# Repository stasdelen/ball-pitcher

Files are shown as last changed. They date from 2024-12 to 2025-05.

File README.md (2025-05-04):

# KingPong

Automatic table-tennis ball pitcher machine, developed as the main assignment of ME407 – Mechanical Engineering Design at Middle East Technical University. Designed to let a single player practice with realistic spin, speed and trajectory control.

## Media

### Team Demo at METU Showcase  
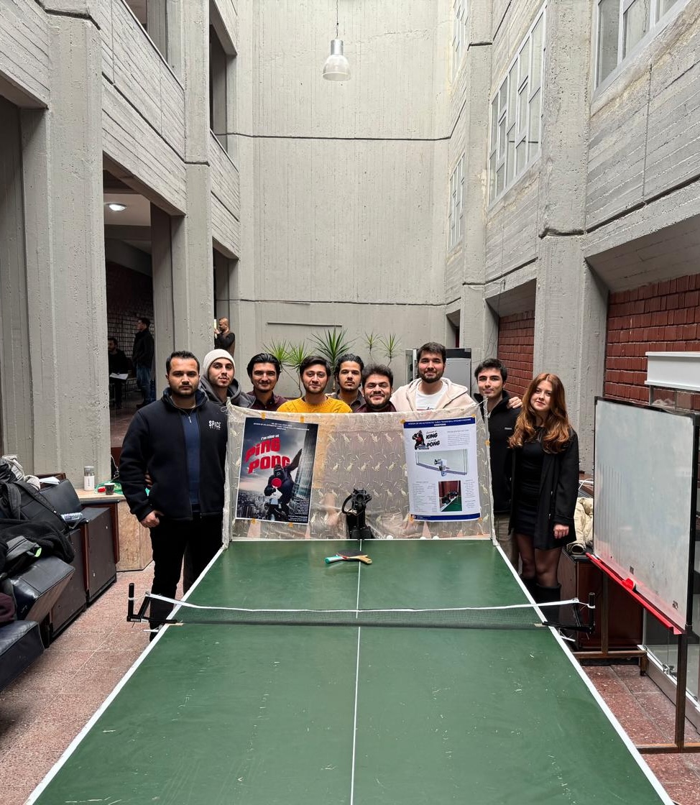
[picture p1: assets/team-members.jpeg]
Team Demo at METU Showcase
  
*The ME407 design group presenting their automatic table-tennis ball pitcher, KingPong, at the METU Mechanical Engineering Department exhibit.*

### METU Mechanical Engineering LinkedIn 
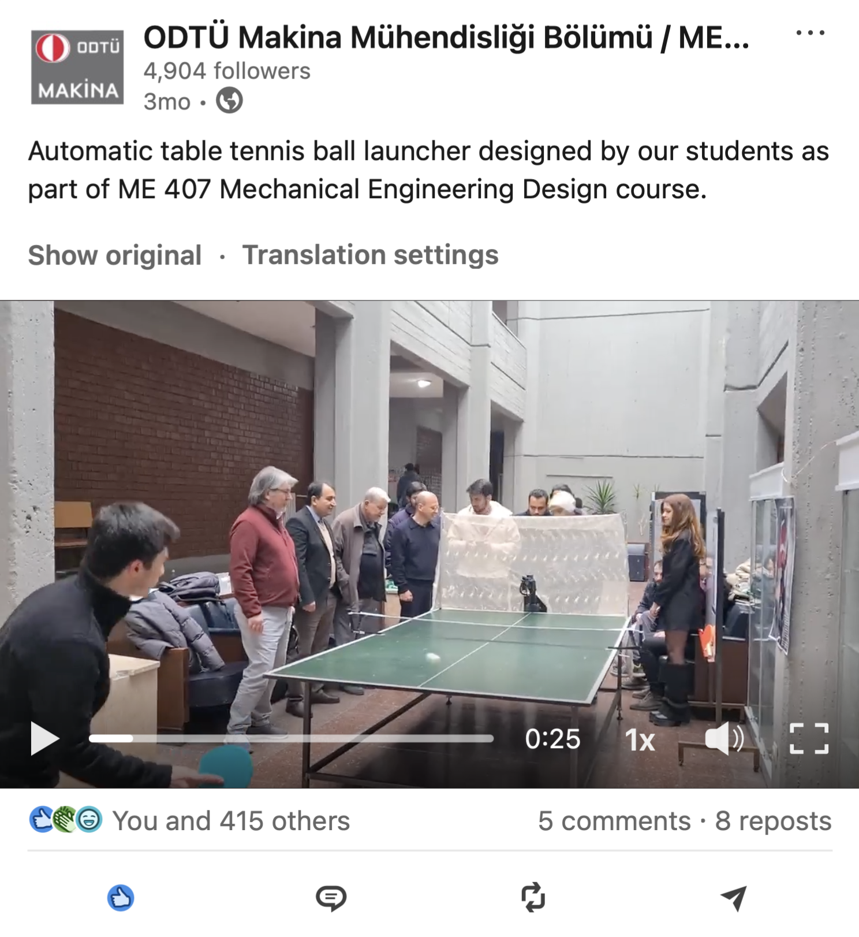
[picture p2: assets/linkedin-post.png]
METU Mechanical Engineering LinkedIn (https://www.linkedin.com/posts/odt%C3%BC-makina-m%C3%BChendisli%C4%9Fi-b%C3%B6l%C3%BCm%C3%BC-metu-department-of-mechanical-engineering_%C3%B6%C4%9Frencilerimizin-me-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)


### Pitching Mechanism Close-Up  
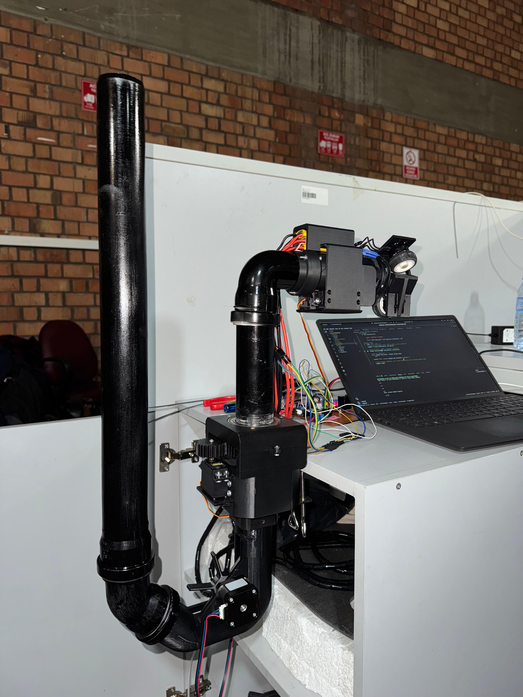
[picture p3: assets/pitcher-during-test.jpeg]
Pitching Mechanism Close-Up
  
*Detailed view of the dual-wheel launcher assembly with servo-driven feeder, control wiring, and live parameter tuning via the host laptop.*

### Mode Shape 3: Modal Analysis Result

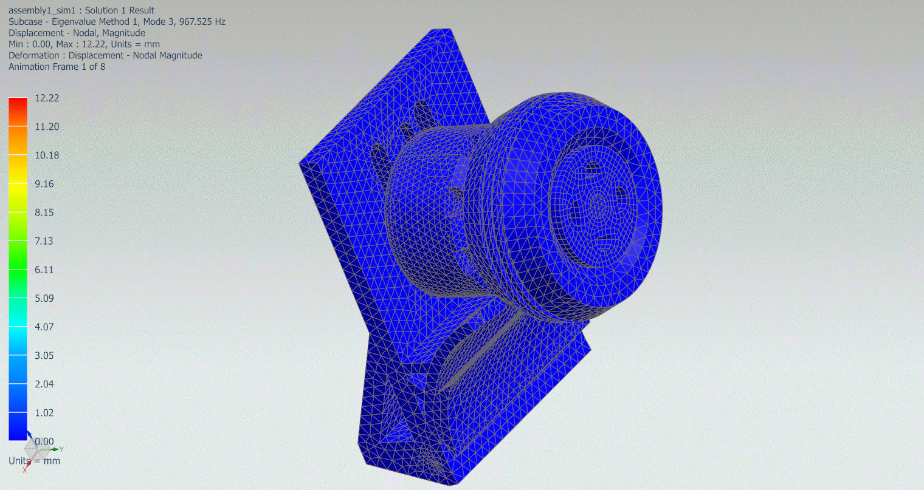
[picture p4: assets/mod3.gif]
Mode Shape 3 – Modal Analysis Result


*Figure: Mode shape 3 from the modal analysis of the spinning‐wheel assembly, illustrating the natural vibration pattern at its associated eigenfrequency.*

## Repository Structure

- **hardware/**  
  CAD models, mechanical drawings and BOM for the launcher, feeder and frame  
- **software/**  
  • `firmware/` Arduino code for motor, servo and sensor control  
  • `host/` Python scripts for remote parameter tuning and logging  
- **reports/**  
  Final report (FR_C1.pdf) and supporting calculations, test plans and sustainability analysis  
- **workshops/**  
  Presentation slides and in-class exercise materials  
- `.gitignore` Standard excludes for build artifacts  
- `.gitattributes` Line endings and diff settings  
- `LICENSE` MIT License  

## Key Features

- **Speed & Frequency** Adjustable launch speed up to 30 m/s and firing rate up to 60 balls/min  
- **Spin Control** Topspin, backspin, sidespin, or any combination of spins (and a no-spin “flat” option) via independent wheel speeds  
- **Trajectory** Pitch range 0 → –20°; yaw range ± 20°  
- **Capacity & Recycling** Reservoir holds ≥ 60 balls; returned balls are automatically fed back  
- **Size & Weight** Fits within 1 m³; total mass ≤ 25 kg  
- **Power** Runs on standard 220–240 V mains; < 2 kW peak consumption  

## Getting Started

1. **Assemble hardware** following the step-by-step CAD drawings in `hardware/`.  
2. **Flash firmware**: open `software/firmware/` in the Arduino IDE and upload to your controller board.  
3. **Launch host interface**: run `python3 software/host/control.py` to connect via USB or Wi-Fi and set speed, spin, pitch and yaw.  
4. **Consult report** in `reports/FR_C1.pdf` for detailed design rationale, calculations and test results.  

## Authors

- Abdullah Can Seyhanlı  
- Altay Ata Ateş  
- Arman Utku Aydın  
- Bilal Açıksöz  
- Kutay Can Yapıcı  
- Ömer Aslan  
- Özge Dilan Tuna
- Abdullah Salih Taşdelen  
- Yunus Emre Özçelik  

## License

This project is released under the MIT License.

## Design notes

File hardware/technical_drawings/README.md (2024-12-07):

# Technical Drawings of the Ball Pitcher

This folder contains the drafts/technicals drawings of the components and assemblies

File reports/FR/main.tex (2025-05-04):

\documentclass[12pt]{report}
\usepackage{graphicx} % For including graphics
\usepackage{hyperref} % For URLs and hyperlinks
\usepackage{amsmath} % For math symbols
\usepackage{enumitem} % For customized lists
\usepackage{geometry} % For page margins
\usepackage{xcolor} % For colored text
\usepackage{titlesec} % For title formatting
\usepackage{fancyhdr} % For headers
\usepackage{setspace} % For spacing
\usepackage{graphicx}
\usepackage{multirow}
\usepackage{adjustbox} % For scaling the table
\usepackage{array} % For defining column widths and centering
\usepackage{rotating}
\usepackage{pdfpages}

\usepackage{geometry} % For margin adjustments
\usepackage{booktabs} % For better looking tables
\usepackage{caption}
\usepackage{subcaption}
\usepackage{float}
\usepackage{rotating}      % For sideways tables
\usepackage{tabularx}      % For automatically adjusting column widths
\usepackage{enumitem}      % For controlling list spacing
\usepackage{placeins}  % For \FloatBarrier
\usepackage{caption}
\setcounter{tocdepth}{4}
\setcounter{secnumdepth}{4}

  %burası inş bozmaz bişi deniyorum şu an
\titleformat{\chapter}[hang]
  {\normalfont\huge\bfseries} % Yazı tipi ve boyutu
  {\thechapter}               % just numaraaa
  {1em}                       % bosluk
  {}                          % without ön ek
  %burası inş bozmaz bişi deniyorum şu an
  
% Page setup
\geometry{a4paper, margin=0.75in} % Adjust margins to allow more space
\setlength{\parindent}{0pt} % Remove indentation
\captionsetup{font=scriptsize}  % Change 'small' to any size: footnotesize, scriptsize, etc.

\renewcommand{\arraystretch}{1.2} % Adjusts the row height

% Title formatting with indentation for sections
% \titleformat{\section}{\bfseries\large\hspace*{1cm}}{\thesection.}{1em}{}
% \titleformat{\subsection}{\bfseries\hspace*{1cm}}{\thesubsection.}{1em}{}
% \titleformat{\subsubsection}{\bfseries\hspace*{2cm}}{\thesubsubsection.}{1em}{}

% Adjust paragraph indentation
\newenvironment{indentedsection}{
    \setlength{\parindent}{1cm} % Indent paragraphs
    \setlength{\leftskip}{1cm} % Indent entire section content
}{}

% Header setup
\pagestyle{fancy}
\fancyhf{}

\fancyhead[R]{\thepage}

% Horizontal line
\renewcommand{\headrulewidth}{0.4pt}

% Begin Document
\begin{document}

\vspace{1cm}

% METU Logo and Title
\begin{center}
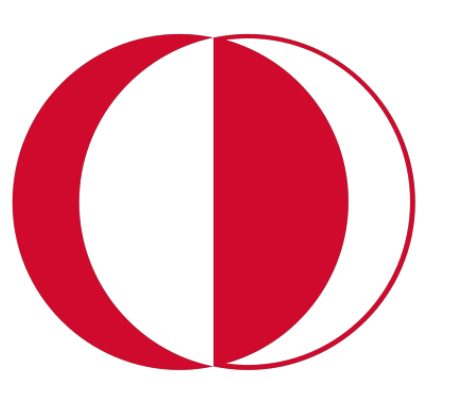
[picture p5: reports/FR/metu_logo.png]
     \\ % Replace "metu_logo.png" with the METU logo file
    \vspace{0.5cm}
    \textbf{\Large TABLE TENNIS BALL PITCHER MACHINE} \\
    \vspace{1cm}
\end{center}

% Report Title Section
\begin{center}
    \textbf{\Huge Final Report} \\
    \vspace{0.5cm}
    %\textbf{\large Subtitle (if any)} \\
    \vspace{1cm}
\end{center}

% Course and Instructor Details
\noindent
\textbf{Course Code and Name:} ME407 Mechanical Engineering Design \\
\textbf{Instructor:} Gökhan Özgen \\
\textbf{Semester:} Fall 2024 \\
\textbf{Date:} 10.01.2025 \\
\vspace{1cm}

% Group Member Details
\noindent
\textbf{Prepared by:}
\vspace{0.5cm}

\begin{center}
\scriptsize
    \begin{tabular}{|p{2cm}|p{1.5cm}|p{4cm}|p{2cm}|p{5cm}|}
        \hline
        \textbf{Name} & \textbf{Student Number} & \textbf{Student E-Mail} & \textbf{Phone Number} & \textbf{Adress}\\ \hline
        Abdullah Can Seyhanlı & 2446821 & abdullah.seyhanli@metu.edu.tr & +905346688387 & Üniversiteler Mah. ODTÜ 8. Yurt 312/3 Ankara/Çankaya \\ \hline
        Altay Ata Ateş & 2445476 & altay.ates@metu.edu.tr & +905422322415 & Üniversiteler Mahallesi ODTÜ Kümeevleri NO: 58 ( Refika Aksoy Yurdu ) Çankaya/Ankara \\ \hline
        Arman Utku Aydın & 2445492 & utku.aydin@metu.edu.tr & +905375432848 & İşçi blokları mahallesi 1538/1. sokak No:23 Daire:6 \\ \hline
        Bilal Açıksöz & 2445286 & bilal.aciksoz@metu.edu.tr & +905437451151 & Kavacık Subayevleri mah. Ergün sok. No:14/2 Keçiören/Ankara \\ \hline
        Kutay Can Yapıcı & 2447084 & kutay.yapici@metu.edu.tr & +905383026603 & Karşıyaka mah. 464. sok. No:24/99 Gölbaşı/Ankara \\ \hline
        Ömer Aslan & 2445443 & omer.aslan\_01@metu.edu.tr & +905532456710 & Üniversiteler Mah. ODTÜ 19.Yurt 329/2 Çankaya/Ankara \\ \hline
        Özge Dilan Tuna & 2446987 & ozge.tuna@metu.edu.tr & +905532611838 & Anadolu Blv. Mehmet Akif Ersoy Mah. Yeşilay Cad. No:5 Yenimahalle/Ankara \\ \hline
         Abdullah Salih Taşdelen & 2446904 & salih.tasdelen@metu.edu.tr & +905541371310 & Yeni Etlik Cad. No: 84/9 Kecioren/Ankara \\ \hline
        Yunus Emre Özçelik & 2268803 & ozcelik.yunus@metu.edu.tr&+905529200972 & Yüzbaşı Mustafa Ertuğrul Cd. Şeker Mah. Eryaman Etimesgut/Ankara \\ \hline
    \end{tabular}
\end{center}

\vfill

% Footer Section
\begin{center}
    \textbf{Location: Ankara, Turkey}
\end{center}

\tableofcontents

\section*{Nomenclature}
\begin{table}[H]
\centering
\begin{tabular}{|c|l|}
\hline
\textbf{Symbol} & \textbf{Description} \\ \hline
$\omega$        & Angular velocity          \\ \hline
$V$             & Linear velocity           \\ \hline
$r$             & Radius                    \\ \hline
$s$             & Slip amount               \\ \hline
$I$             & Inertia                   \\ \hline
$t$             & Time                      \\ \hline
$E_p$           & Potential Energy          \\ \hline
$P$             & Power, Load               \\ \hline
$\alpha, \theta$ & Angle                     \\ \hline
$m$             & Mass, Module              \\ \hline
$F$             & Force                     \\ \hline
$z$             & Teeth number              \\ \hline
$d$             & Diameter                  \\ \hline
$b$             & Face width                \\ \hline
$h$             & Working depth             \\ \hline
$h_a$           & Addendum                  \\ \hline
$h_f$           & Dedendum                  \\ \hline
$R_{xy}$        & Gear ratio                \\ \hline
$X, Y$          & Load factor               \\ \hline
$n$             & Rotational speed (rpm)    \\ \hline
$v$             & Viscosity                 \\ \hline
$T$             & Temperature, Torque       \\ \hline
$A$             & Area                      \\ \hline
$C$             & Basic dynamic load rating \\ \hline
$p$             & Exponent of life equation \\ \hline
$L$             & Basic rating life         \\ \hline
$g$             & Acceleration due to gravity \\ \hline
$\text{FoS}$    & Factor of safety          \\ \hline
$\text{UTS}$    & Ultimate tensile strength \\ \hline
$S_y$           & Yield strength            \\ \hline
$J$             & Polar moment of inertia   \\ \hline
$\sigma$        & Stress                    \\ \hline
$E$             & Elastic modulus           \\ \hline
$k$             & Stiffness                 \\ \hline
$l$             & Length                    \\ \hline
$n_b$           & Safety factor             \\ \hline
$n_o$           & Separation factor         \\ \hline
$M$             & Bending moment            \\ \hline
\end{tabular}
\caption{Symbols and their Descriptions}
\label{tab:symbols}
\end{table}
\section*{Lists}

\begin{table}[h!]
\centering
\begin{tabular}{|p{15cm}|}
\hline
\textbf{List of Tables} \\ \hline
Table 4.1: Comparison of Table Tennis Robots \\ \hline
Table 5.1: The Members of the Project \\ \hline
Table 5.2: Timetable Showing Workload Distribution \\ \hline
Table 7.1: Yaw Angle Components \\ \hline
Table 7.2: Feeding System Components \\ \hline
Table 7.3: Decisions Based on Meeting the Performance Criteria Target (Part 1) \\ \hline
Table 7.4: Decisions Based on Meeting the Performance Criteria Target (Part 2) \\ \hline
Table 7.5: Gear Dimensions \\ \hline
Table 7.6: Decisions Based on Meeting the Performance Criteria Target (Part 3) \\ \hline
Table 7.7: Specifications of the 17HS3401S Motor \\ \hline
Table 7.8: Failure Scenarios and Related Design Parameters \\ \hline
Table 7.9: List of Final Values of Design Decisions and Parameters\\ \hline
Table 10.1: Cost Analysis \\ \hline
\end{tabular}
\caption{List of Tables}
\label{tab:list_of_tables}
\end{table}

\begin{table}[h!]
\centering
\begin{tabular}{|p{15cm}|}
\hline
\textbf{List of Figures} \\ \hline
Figure 4.1: Table tennis equipment wholesale sales in the U.S. from 2007 to 2023 [7] \\ \hline
Figure 4.2: Sectional view of the ball feeding flow from the reservoir to launch unit in AIMY [9] \\ \hline
Figure 4.3: General System Description [1] \\ \hline
Figure 4.4: General schematic of
serving machine [2] \\ \hline
Figure 4.5: Side view and detailed
mechanism of table tennis robot [3] \\ \hline
Figure 4.6: Orthogonal and general views of the table tennis robot [3] \\ \hline
Figure 4.7: General System Description [4] \\ \hline
Figure 4.8: Lower to Upper-Level Reservoir Feeding System [5] \\ \hline
Figure 5.1: Gantt Chart \\ \hline
Figure 6.1: Functional Decomposition \\ \hline
Figure 6.2: Free body diagram of the ball \\ \hline
Figure 6.3: Criteria vs Criteria Evaluation
\\ \hline
Figure 6.4: Criteria vs Criteria Evaluation Normalized \\ \hline
Figure 6.5: Giving spin to the ball \\ \hline
Figure 6.6: Controlling the spin \\ \hline
Figure 6.7: Giving speed to the ball \\ \hline
Figure 6.8: Controlling the speed \\ \hline
Figure 6.9: Giving yaw angle to the launching mechanism \\ \hline
Figure 6.10: Controlling the yaw angle \\ \hline
Figure 6.11: Giving pitch angle to the launching mechanism \\ \hline
Figure 6.12: Controlling the pitch angle \\ \hline
Figure 6.13: Accepting frequency information from the user \\ \hline
Figure 6.14: Accepting numerical information from the user \\ \hline
Figure 6.15: Accepting trajectory information from the user \\ \hline
Figure 6.16: Allowing the user to position the device \\ \hline
Figure 6.17: Preventing balls from escaping \\ \hline
Figure 6.18: Storing the balls \\ \hline
Figure 6.19: Transferring the balls from the storage \\ \hline
Figure 6.20: Controlling the ball feed for storage \\ \hline
Figure 6.21: Transferring the balls to launch \\ \hline
Figure 6.22: Controlling the ball feed for launching \\ \hline
Figure 6.23: Giving the balls desired frequency \\ \hline
Figure 6.24: Controlling the ball frequency
\\ \hline
Figure 6.25: Concept Evaluation Normalized[6] \\ \hline
Figure 6.26: Feeder side view\\ \hline
Figure 6.27: Side view \\ \hline
Figure 6.28: Front View \\ \hline
Figure 6.29: Orthogonal view \\ \hline

\end{tabular}
\caption{List of Figures (Part 1)}
\label{tab:list_of_figures_part1}
\end{table}

\begin{table}[h!]
\centering
\begin{tabular}{|p{15cm}|}
\hline
\textbf{List of Figures} \\ \hline
Figure 7.1: Launcher Subassembly \\ \hline
Figure 7.2: Pitch angle subassembly \\ \hline
Figure 7.3: Yaw angle subassembly \\ \hline
Figure 7.4: 6810 ZZ Bearing \\ \hline
Figure 7.5: Feeding system subassembly \\ \hline
Figure 7.6: Socket head bolt \\ \hline
Figure 7.7: Set screw \\ \hline
Figure 7.8: Ball Recyclability system \\ \hline
Figure 7.9: Storage system subassembly \\ \hline
Figure 7.10: Clamp \\ \hline
Figure 7.11: FBD of launcher subassembly \\ \hline
Figure 7.12: Gear kinematics \\ \hline
Figure 7.13: Calculation factors for deep groove ball bearings \\ \hline
Figure 7.14: Rated viscosity estimation table \\ \hline
Figure 7.15: Viscosity value table\\ \hline
Figure 7.16: a\_skf factor\\ \hline
Figure 7.17: Selection of a1 factor\\ \hline
Figure 7.18: Free-body diagram of Maltese wheel\\ \hline
Figure 7.19: Model of inclined groove\\ \hline
Figure 7.20: Buckling condition constants\\ \hline
Figure 7.21: FBD of Bolt\\ \hline
Figure 7.22: FBD of the Clamp Connection\\ \hline
Figure 7.23: Analysis result of feeding holder\\ \hline
Figure 7.24: Analysis result of Maltese wheel\\ \hline
Figure 7.25: Analysis result of main body below part\\ \hline
Figure 7.26: Analysis result of upper elbow\\ \hline
Figure 7.27: Analysis result of the pitch angle fixed part\\ \hline
Figure 7.28: Main flow chart\\ \hline
Figure 7.29: BLDC Motor Control flow chart\\ \hline
Figure 7.30: Stepper motor control flow chart\\ \hline
Figure 7.31: Yaw and pitch angle control flow chart\\ \hline
Figure 7.32: Results of the Environmental Impact Analysis\\ \hline
Figure 11.1: Storing Mechanisms\\ \hline
Figure 11.2: Transferring the balls from storage\\ \hline
Figure 11.3: Giving the balls desired frequency\\ \hline
Figure 11.4: Net\\ \hline
Figure 11.5: Gravity Mechanism\\ \hline
Figure 11.6: Giving spin and speed to the balls\\ \hline
Figure 11.7: Giving pitch angle to the launching mechanism\\ \hline

\end{tabular}
\caption{List of Figures (Part 2)}
\label{tab:list_of_figures_part2}
\end{table}
\begin{table}[h!]
\centering
\begin{tabular}{|p{15cm}|}
\hline
\textbf{List of Figures} \\ \hline
Figure 11.8: Giving yaw angle to the launching mechanism\\ \hline
Figure 11.9: Accepting spin and frequency information from the user\\ \hline
Figure 11.10: Accepting speed information from the user\\ \hline
Figure 11.11: Clamps\\ \hline
Figure 11.12: Technical drawing of the assembly of the system\\ \hline
Figure 11.13: Technical drawing of the feeding holder\\ \hline
Figure 11.14: Technical drawing of the yaw motor housing\\ \hline
Figure 11.15: Technical drawing of the hole bearing cap\\ \hline
Figure 11.16: Technical drawing of the storage\\ \hline
Figure 11.17: Technical drawing of the feeding line to storage\\ \hline
Figure 11.18: Technical drawing of the flywheel\\ \hline
Figure 11.19: Technical drawing of the groove\\ \hline
Figure 11.20: Technical drawing of the keyway bushing for yaw mechanism\\ \hline
Figure 11.21: Technical drawing of the bottom part of the main body\\ \hline
Figure 11.22: Technical drawing of the upper part of the main body\\ \hline
Figure 11.23: Technical drawing of the Maltese wheel\\ \hline
Figure 11.24: Technical drawing of the slotted pipe for the launcher head\\ \hline
Figure 11.25: Technical drawing of the pipe attachment for launcher head\\ \hline
Figure 11.26: Technical drawing of the motor attachment for the launcher head\\ \hline
Figure 11.27: Technical drawing of the fixed part for pitch angle\\ \hline
Figure 11.28: Technical drawing of the moving part for pitch angle\\ \hline
Figure 11.29: Bill of materials to be bought\\ \hline
Figure 11.30: Bill of materials to be manufactured\\ \hline
Figure 11.31: Route sheets for the components\\ \hline
Figure 11.32: Control schematic of the system\\ \hline

\end{tabular}

\caption{List of Figures (Part 3)}
\label{tab:list_of_figures_part3}
\end{table}

\chapter{Abstract}
This project is performed as the main assignment of the course ME407 Mechanical Engineering Design at Middle East Technical University. Purpose of this course is to familiarize the students in their final year with the processes of engineering design, enhance their problem solving and decision-making skills, introduce them to the use of different software tools for design, and teach them planning, management and teamwork. The objective for this project is to design an Automatic Table Tennis Ball Pitcher Machine suitable to use for players of all ages and skill levels to practice on their own. First, a literature survey is conducted to study the existing products on the market, state of the art technologies and the patents related to the project. Then the requirements of the project are determined considering the goal, including but not limited to being able to give different spin options, varying yaw and pitch angles and different speeds. The design criteria are then set according to these requirements. Next, the planning for the management for the project is done, where tasks are assigned to each group member according to their different capabilities. In the conceptual design process, different concepts and ideas to perform the necessary functions are created and evaluated. A functional decomposition is performed and a morphological chart is constructed for this purpose, and the evaluation is performed using Analytic Hierarchy Process method. The resultant design is named the best design for the project, and the detailed design process is initiated. The detailed design process consists of performing the necessary analyses and calculations for the parts and components that fulfill the functions as decided on the best design to justify their working mechanisms, performing the optimization procedures where they are due, conducting the necessary tests and finally the manufacturing and assembly of these parts and the whole system in general. The whole process is documented along the way, with the technical drawings of the project, the machine elements used, the standards followed, the cost analysis and sustainability report. This project presented an important opportunity to work on a real-life engineering case, and get acquainted with the hardships and scenarios encountered in practical applications. The experience gained along the way is valuable for all members involved.
\chapter{Özet}
Bu proje, Orta Doğu Teknik Üniversitesi’nde ME407 Makina Mühendisliği Dizaynı dersinin ana görevi olarak yapılmıştır. Bu dersin amacı, son senesindeki öğrencileri mühendislik dizaynı süreçlerine alıştırmak, problem çözme ve karar alma becerilerini geliştirmek, dizayn için çeşitli yazılım araçlarının kullanımıyla tanıştırmak ve onlara planlama, yönetim ve takım çalışmasını öğretmektir. Bu projenin amacı, her yaştan ve beceri düzeyinden oyuncunun kendi başına pratik yapabilmesi için kullanıma uygun bir Otomatik Masa Tenisi Topu Fırlatıcısı makinesi dizayn etmektir. Öncelikle, projeyle alakalı piyasada var olan ürünleri, son teknolojileri ve patentleri incelemek için bir literatür taraması gerçekleştirilmiştir. Sonrasında, projenin amacı göz önünde bulundurularak, topa farklı dönüş opsiyonları, değişken yatay ve dikey fırlatış açıları ve farklı hızlar vermeyi içeren, fakat bunlarla sınırlı olmayan gereksinimlere karar verilmiştir. Sonrasında bu gereksinimlere göre dizayn kriterleri oluşturulmuştur. Sonrasında, her grup üyesine farklı kabiliyetlerine uygun görevlerin verildiği, projenin yönetimi için gereken planlama yapılmıştır. Konsept dizaynı sürecinde, gerekli fonksiyonları gerçekleştiren farklı konseptler ve fikirler oluşturulup değerlendirilmiştir. Bu amaç için bir hiyerarşik ayrıştırma yapılmış ve bir morfolojik şema oluşturulmuş, değerlendirme için de Analitik Hiyerarşi Süreci metodu kullanılmıştır. Sonuçlanan dizayn en iyi dizayn olarak adlandırılmış, ve detaylı dizayn süreci başlamıştır. Detaylı dizayn süreci, en iyi dizaynda karar verildiği gibi fonksiyonları gerçekleştiren kısım ve parçaların çalışma mekanizmalarını doğrulamak için gerekli analizlerin ve fonksiyonların yapılmasından, gereken yerlerde optimizasyon prosedürlerinin uygulanmasından, gerekli testlerin gerçekleştirilmesinden ve nihayetinde bu kısımların ve genel sistemin üretimi ve montajından oluşmaktadır. Bütün bu süreç aynı zamanda teknik çizimlerle, kullanılan makine elemanlarıyla, takip edilen standartlarla, maliyet analiziyle ve sürdürülebilirlik raporuyla birlikte belgelendirilmiştir. Bu proje, gerçek bir mühendislik vakasında çalışmak, ve pratik uygulamada karşılaşılan zorluk ve senaryolarla tanışmak konusunda önemli bir imkan sunmuştur. Bu süreçte kazanılan deneyim, dahil olan tüm üyeler için önemlidir.

\chapter{Introduction}

Table tennis is a sport that keeps rising in popularity day by day, as it can be easily enjoyed by all age groups, and the rules are easy to pick up. Aside from being an Olympic sport, it is also
widely played as a hobby by a large number of people, and some studies even suggest that for
children and the elderly, the sport has various physical and mental health benefits. Taking these
into consideration, it can be seen in \ref{fig:intro} that the demand for the sport is increasing each year.
\begin{figure}[h!]
    \centering
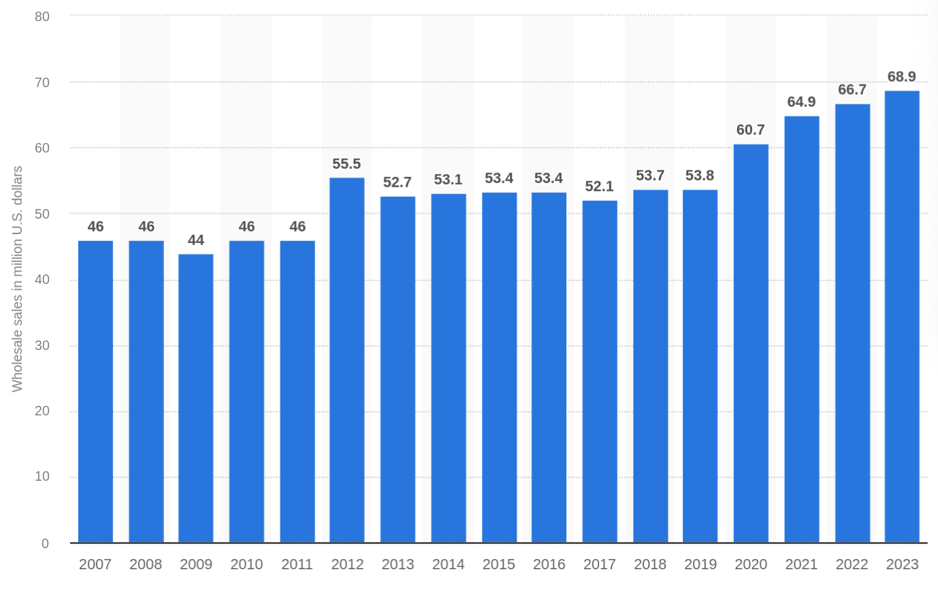
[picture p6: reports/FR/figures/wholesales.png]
    
    \caption{Table tennis equipment wholesale sales in the U.S. from 2007 to 2023 \cite{statista2024}}
    \label{fig:intro}
\end{figure}

For such a popular sport that spans from a professional and competitive scene to a leisure time hobby for a large demographic, a prominent issue may be expressed as its requirement of two people to be played. A willing partner to practice with may not be readily available at all times, and this poses a problem for both professional players who need to practice and hone their skills for competition, and the general population who seek to play it for various reasons ranging from pastime hobby to a healthy lifestyle. For this reason, the need for a product that allows people to practice the sport on their own is apparent. However, the already existent products on the market are either too expensive to serve a broader customer population or lack some features that may result in a poorer experience. This project aims to fill the gap and create a table tennis ball pitching machine suitable for players of all skill levels, from amateur to professional.

To accomplish this goal and imitate a real play experience as closely as possible, certain requirements should be met. These requirements include but are not limited to, the machine being able to automatically adjust its yaw and pitch angles, perform simple and basic pitches while also being able to give various spin options, launch the ball at different speeds and frequencies, as well as switching between these variations automatically. The machine should also be able to store a minimum number of balls, and recycle successfully returned balls into the system via some mechanism. Considering these requirements, design specifications and criteria can be constructed as follows:

\begin{itemize}
    \item The ball must reach a maximum speed of 30 m/s during launch. It must be adjustable within this range.
    \item The ball’s launch frequency must provide 60 balls per minute. It must be adjustable within this range.
    \item The ball must be able to be given spin up to 500 RPM, including backspin, topspin, sidespin, and their derivatives. This spin value must be independent of speed.
    \item The launcher must provide launch with a yaw angle within a range of ±20 degrees horizontally.
    \item The launcher must provide launch with a pitch angle within a range of 0 to -20 degrees vertically.
    \item A storage area that can accommodate a minimum of 60 balls is required.
    \item The maximum weight of the entire system must not exceed 25 kilograms.
    \item The system is securely fastened to the table or floor in the middle of the opponent’s side of the ITTF standard table, at the center of the width of the table. The maximum displacement after 50 throws shall be 20 mm.
    \item The lifetime of a single ball in the cycle should be at least 1000 throws.
    \item The system must have a user interface allowing launch parameter configuration with a maximum 10\% deviation.
    \item The design can collect the properly returned balls from the player. Recyclable ball height needs to be at least 1 meter.
    \item The system is compliant with ITTF table and ball dimensions:
    \begin{itemize}
        \item Suitable for a 2.74 m long and 1.525 m wide table.
        \item Can serve over a 15.25 cm high net.
        \item Suitable for standard table tennis balls with a 2.7-gram weight and 40 mm diameter.
    \end{itemize}
    \item The machine should operate on standard mains electricity (220-240V, 50-60 Hz). Also, it should not consume more than 2000W.
    \item Total spending for the prototype of the design should be kept within 300 USD.
    \item The design, when unassembled, should fit inside a 1 m\textsuperscript{3} box.
    \item \textbf{(Bonus)} The ball must be able to be thrown without spin.
    \item \textbf{(Bonus)} The ball is first bounced by the shooter, giving the user the experience of serving.
\end{itemize}

\begin{table}[H]
\centering
\begin{tabular}{|c|p{7cm}|c|}
\hline
\textbf{\#} & \textbf{Design Criteria} & \textbf{Percentage} \\ \hline
1 & Serving Speed & 13\% \\ \hline
2 & Throwing Frequency & 13\% \\ \hline
3 & Spin Type and Amount & 10\% \\ \hline
4 & Yaw Angle Adjustment & 7\% \\ \hline
5 & Pitch Angle Adjustment & 7\% \\ \hline
6 & Storage Capacity & 6\% \\ \hline
7 & Weight & 4\% \\ \hline
8 & Stability of the System & 6\% \\ \hline
9 & Ball Durability & 4\% \\ \hline
10 & Control Accuracy and Output Consistency & 7\% \\ \hline
11 & Ball Recyclability & 5\% \\ \hline
12 & Compliancy with Standards & 3\% \\ \hline
13 & Power Consumption & 3\% \\ \hline
14 & Budget & 8\% \\ \hline
15 & Portability & 4\% \\ \hline
16 & No Spin Option (Bonus) & 5\% \\ \hline
17 & Special Serving (Bonus) & 5\% \\ \hline
\end{tabular}
\caption{Design Criteria and Their Percentages}
\label{tab:design_criteria}
\end{table}

The design for this project starts with a thorough literature survey conducted on products on the market, state-of-the-art technologies and patents related. Then, a detailed task distribution and management plan is done spanning the whole project process, which helps lay out a road map and makes it easier to organize and handle the work for further down the line. The conceptual design starts at this point, where ideas and concepts begin to appear, which are listed and evaluated using methods such as performing functional decomposition, creating a morphological chart and passing them through Analytical Hierarchy Process. After a best design is chosen through these processes, the detailed design part is initiated. In this part, necessary analyses and calculations are performed to justify the design, the test plans are made and test are carried out, and components and parts are manufactured accordingly. Optimization processes are done where necessary. At the end of this part, a fully assembled and working system is expected to be constructed. The whole design process is documented from start to finish, with important information such as technical drawings, cost analysis and sustainability report included, to create a clear and concise report so as the design process and the design itself could be understood. 

This final report is the combination of all the reports created up until this point for different parts of the design process. A discussion and conclusion is given at the end of the report, where the final product is discussed, and conclusions derived are mentioned. The references part, where the sources made use of and referred and the appendix part, where the necessary appendices are presented are also given at the end. The outline of the final report is given as,

\begin{enumerate}
    \item \textbf{Abstract}
    \item \textbf{Introduction}
    \item \textbf{Literature Survey}
    \begin{enumerate}
        \item[a.] Introduction
        \item[b.] Commercial Products
        \item[c.] State-of-the-art on Related Technologies
        \item[d.] Patents
        \item[e.] Summary and Conclusion
    \end{enumerate}
    \item \textbf{Project Planning and Management}
    \begin{enumerate}
        \item[a.] Introduction
        \item[b.] Organization of the Project
        \item[c.] Summary and Conclusion
    \end{enumerate}
    \item \textbf{Conceptual Design}
    \begin{enumerate}
        \item[a.] Introduction
        \item[b.] Concept Development and Presentation
        \item[c.] Evaluation of Concepts
        \item[d.] Best Concept
        \item[e.] Summary and Conclusion
    \end{enumerate}
    \item \textbf{Detailed Design}
    \begin{enumerate}
        \item[a.] Introduction
        \item[b.] Properties of the Designed System
        \item[c.] Engineering Calculations
        \item[d.] Analysis Results
        \item[e.] Discussion of Control Algorithms and Software
        \item[f.] Optimization
        \item[g.] System to be Manufactured
        \item[h.] Sustainability Analysis
        \item[i.] Test Plan
        \item[j.] Standards Used for Design Procedures and Performance Evaluation
        \item[k.] Discussion and Conclusion
    \end{enumerate}
    \item \textbf{Discussion}
    \item \textbf{Conclusion}
    \item \textbf{References}
    \item \textbf{Appendix}
\end{enumerate}

\chapter{Literature Survey}

% Main title and keyword section
\begin{center}
    \vspace{1em} % Add some space
    \vspace{1em} % Add some space
    \textbf{KEYWORDS: Table Tennis, Ball Thrower, Ball Collector, Trajectory Control, Ping Pong Spin}
\end{center}

% Start of sections
\section{Introduction}

For this project of a table tennis pitching machine, a detailed literature survey that includes the research of commercial products available in the market, state of the art technologies and the patents is conducted. As the market for table tennis is wide and open for profit, there are already numerous of products and technologies on how to approach different aspects of the project.\\

For commercial products, different table tennis ball pitching machines on the market are observed and analyzed to get an idea about their capabilities and shortcomings. It is necessary to choose which features to implement based on the demand of the market and the cost-effectiveness of the end product. \\

The state-of-the-art technologies are plenty for this project at hand, as there are multiple functions the machine must be able to perform. For aspects of launching, feeding itself from a reservoir, adjusting the speed and frequency etc., different kind of devices and mechanisms that can be used are investigated. \\

Lastly, patents are an important part of the research, as intellectual properties must be respected, and should be taken into consideration so as to ensure the proceeding of the project does not raise any issues with copyright infringement.

\section{Commercial Products}

\begin{minipage}{0.6\textwidth}
    The table tennis table market is a vibrant sector in the sports and recreation sector, appealing to a variety of consumers from amateur players to professional athletes. The statistics in Figure \ref{fig:commer1} below show the sales figures of table tennis equipment from manufacturers in the United States from 2007 to 2023. Last year, total sales of table tennis equipment in the United States reached approximately \$69 million in 2023. This was an increase of approximately 28\% compared to 2019. Therefore, it is naturally expected that the number of products and manufacturers in the market will increase. Also, according to research conducted by Business Research Insights, the global table tennis table market size was USD 485.3 million in 2022 and the market is expected to reach USD 598.11 million by 2032, growing at a CAGR of 2.1\% during the forecast period \cite{table_tennis_market_2032}.
\end{minipage}
\begin{minipage}{0.38\textwidth}
    \centering
    
    \captionof{figure}{Table tennis equipment wholesale sales in the U.S. from 2007 to 2023 \cite{statista2024}}
    \label{fig:commer1}
\end{minipage}

After careful research, various table tennis ball launcher models starting from \$100 and going up to \$2500 are found. One can see some common models, along with their comparisons in Table \ref{commercial} in Appendix. Of course, there are many differences in features among the devices in this wide price range. While affordable models can launch the ball without turning or by turning it only in one direction, advanced models can send the ball by turning it in 36 different ways. On the contrary, the dimensions of the ball chambers and the launch speeds are independent of the product prices. Almost all of the products, regardless of their prices, have launch speeds between 4 and 40 m/s. \\

In terms of usage, many products have wired or wireless control units. These units provide limited access with the buttons on them. It is seen that only in the highest segment products, the controller is in the form of a phone application. This feature should not be such a luxurious feature. This development may be a situation that is welcomed by many users. In addition, while doing this research it is seen that the ball turning mechanisms of various models are the same. Since the mechanism was the same, different rotations could not be obtained, but the number of rotations was increased by rotating the head section with smaller intervals. The research also shows that the products in this area could be further improved. \\

Several commercial products that serve the same purpose as the project requirements are reviewed. Most of the products are at an acceptable level at meeting the requirements but none of them fully meets the wanted requirements. The required max serving speed of 90 m/s couldn’t be achieved by any of the products. The max achieved speed is 40 m/s. One of the key requirements, the launch frequency, was almost achieved by most products, but fully achieved only by 4 products. These are the products of RoboPong and PowerPong. Considering the overall performance one can see that Robo Pong Super Pro and Robo Pong Pro Digital are the most suitable ones for the project requirements.

\section{State-of-the-Art on Related Technologies}

Recent developments in table tennis ball launchers, outlined in this section, focus on enhancing training efficiency and replicating real-game conditions. The literature survey identifies various studies exploring launch mechanisms and ball feeding systems that improve precision and control over key parameters. These advancements enable more precise training experiences, allowing players to better prepare for actual gameplay. This section states the findings from the literature on the latest innovations in table tennis ball launchers, highlighting their technical specifications and proposing directions for future research and development. 

\subsection{Launch Mechanisms}

Over the years, various pitching mechanisms have been developed, each with unique features designed to cater to different training needs. Among the most common are wheeled, pressurized, and hammered pitching machines  \cite{Lan2024}. Each mechanism offers different benefits, like precise control over ball speed, ability to give spin, adjust ball trajectory or realistic human-like trajectories. Understanding the differences in these machines’ mechanisms is crucial for selecting the right one to suit specific requirements of the project. 

\begin{indentedsection}

\subsubsection{Wheeled Pitching Machines}

Wheeled pitching machines utilize two or more spinning wheels to grip and propel the ball. The speed of the wheels can be adjusted independently, allowing for precise control over both speed and spin \cite{Dittrich2023}. By controlling the rotation speed of each wheel, users can simulate a variety of pitches making wheeled machines suitable for the project. Their ability to precisely control the trajectory, speed, and spin of the ball makes them a popular choice for both professional and amateur training environments (\cite{zxmoto2022}, \cite{amazon2024}, \cite{ipong2022} etc.). These mechanisms are also easier to manufacture compared to other pitching methods since the only moving parts are the wheels that accelerate the ball \cite{Zhang2021}.

\subsubsection{Pressurized Pitching Machines}

Pressurized pitching machines function by using a compressed air system to propel the ball \cite{Wiley1994}. These machines are known for their ability to achieve very high ball speeds, which makes them ideal for practicing fastballs. However, they are limited in their ability to generate spin and control trajectory as effectively as wheeled machines. The air pressure can be adjusted to control the velocity of the pitch, but this type of machine is less versatile for training different types of pitches. Additionally, the need for a reliable air compressor makes these machines bulkier and less portable. 

\subsubsection{Hammered Pitching Machines}

Hammered pitching machines use a mechanical arm or hammer to strike and propel the ball forward. While this method simulates overarm throws or cricket bowling actions, it lacks the fine control over spin and speed that wheeled machines provide. These machines are often used for training where high consistency in delivery is necessary, but their lack of spin manipulation and limited speed control make them less effective for comprehensive training purposes. However, they offer a realistic simulation of  human-like throw, which may be advantageous in certain training scenarios. \\

\end{indentedsection}

Since wheeled mechanisms are superior in speed and trajectory control, the primary focus of the research was on these mechanisms and robots. There are various studies on different wheeled launch mechanisms in the literature. In the study of AIMY \cite{Dittrich2023}, they employed a three-wheel configuration to generate precise ball speeds, up to $15.4 m/s$, and spins up to $192.0 s^{-1}$, similar to professional human players.  Also, the study on table tennis robotic launchers \cite{Jamaludin2022} provides valuable insights into the development of launch mechanisms. The launch unit of table tennis robotic launchers predominantly employs one or two rotating wheels to propel the balls with variable speeds and spins. This system allows for precise control over ball velocities mTTTbot project utilizes two brushless motors connected to silicone wheels in the launch mechanism \cite{Tasci2023}. As noted by Jamaludin et al. \cite{Jamaludin2022}, the robot uses DC motors to generate spin and adjust the launching speed of the balls. By modifying the Pulse Width Modulation (PWM) values, the launch speed and distance can be controlled, which directly impacts the ball’s travel distance and spin during play. Apart from these, there are further studies in the literature not only specific to table tennis but also include diverse launch mechanisms which can also help us in our project. Distinct features in tennis ball machines, as described by Gao, contribute to the launch mechanisms \cite{Gao2019}. In Gao’s study, tennis balls are launched using two friction wheels with a 90 mm diameter and a 3 mm concave depth. These features improve grip and spin control, providing better ball speed and direction. The wheels are powered by 12V motors, allowing adjustable launch speeds and angles for versatile training. The concave design of the friction wheels enhances ball spin and control, making this design competitive with more expensive tennis ball machines.

\subsection{Ball Feeder}

The ball feeding system plays a critical role in maintaining a consistent and uninterrupted supply of balls to the launch mechanism, as demonstrated in several studies. The ball feeder in AIMY’s design offers precise control and reliability with its crank mechanism that converts the rotary motion of a servomotor into linear motion as shown in Fig.2, ensuring continuous feeding without clogging, which is ideal for long-duration training. However, the mechanical complexity may increase manufacturing and maintenance costs \cite{Dittrich2023}. Also, the table tennis robotic launcher described by Jamaludin et al. employs a hopper system that has a high ball storage capacity, between 100 and 300 balls. The balls are delivered via a motorized conveyor belt or a rotating crank system, allowing for adjustable feed rates ranging from 25 to 80 balls per minute \cite{Jamaludin2022}. Apart from these, the mTTTbot project introduces a servo-driven feeding mechanism that continuously delivers balls through a helical channel, preventing interruptions in the training flow. As a drawback, its reliance on continuous servo control could limit durability during extended use \cite{Tasci2023}. According to another study by Jamaludin et al., the ball feeder is driven by a motorized mechanism that supplies balls at a rate of 8 to 15 balls per minute under stationary conditions, although this rate decreases when the robot rotates to aim at different angles \cite{Jamaludin2023}. Expanding on the design concepts, Gao’s research on tennis ball machines includes a turntable mechanism that feeds balls into a guide rail with improved timing and frequency control. This system also prevents blockage between layers, enhancing the reliability of the feeding process during extended practice sessions \cite{Gao2019}. 

\vspace{0.5cm}\begin{figure}[H]
\centering
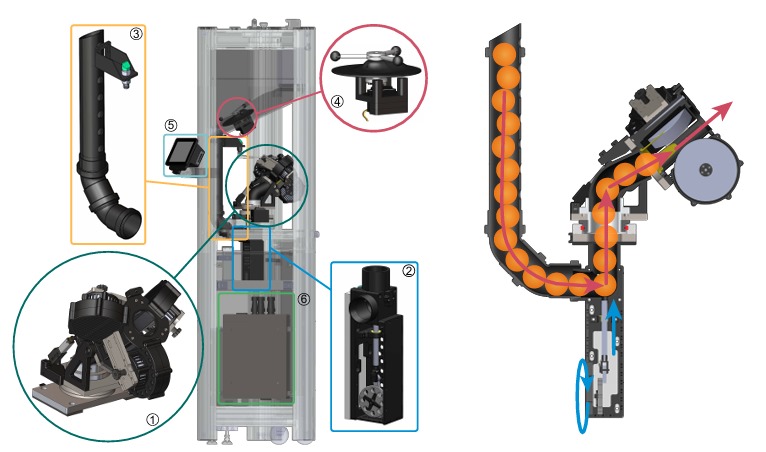
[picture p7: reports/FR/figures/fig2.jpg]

\caption{Sectional view of the ball feeding flow from the reservoir to launch unit in AIMY \cite{Dittrich2023}}
\end{figure}

\subsection{Reservoir}

The reservoir component plays an essential role in ensuring a continuous and uninterrupted supply of balls to the feeding system in robotic launchers. AIMY’s ball feeding system includes an optical sensor that monitors the ball supply and activates a stirrer to prevent clogging, ensuring a smooth flow of balls to the launch unit \cite{Dittrich2023}. In table tennis robotic launchers, as described by Jamaludin et al., the reservoir is designed to store a large number of balls (ranging from 100 to 300) and incorporates mechanisms to prevent clogging, ensuring consistent feeding to the launcher [2]. The mTTTbot system also features a ball reservoir that stores balls before feeding them into the launcher. A stirrer mechanism is integrated to prevent jams, further enhancing the operational reliability of the robot during training sessions [3]. In a study by Jamaludin et al., the ball reservoir is also equipped with a stirrer mechanism to prevent any clogging issues, like the AIMY robot [4]. In the case of tennis ball machines, Gao describes the use of a turntable reservoir with a two-layer design, which can hold up to 12 balls at once. While this design helps to avoid blockages between layers and ensures a smooth feeding process, its limited capacity may require more frequent reloading during prolonged practice sessions [5]. 

\subsection{Control Unit}

The control system is a pivotal component in the functionality of robotic ball launchers, allowing precise adjustments and remote management of the launch parameters. AIMY utilizes a Raspberry Pi as its control unit, enabling low-latency control (500 ms) through Ethernet or Wi-Fi, and providing an interface for integration with reinforcement learning (RL) environments via a Python API [1]. In a related study on table tennis robotic launchers, Jamaludin et al. describe the use of advanced user interfaces, which can be integrated with smartphone applications to control the system wirelessly via Bluetooth or Wi-Fi. These interfaces allow users to pre-program training routines and adjust variables such as spin, speed, and ball frequency for enhanced training realism [2]. The mTTTbot project also adopts an electronic control system that includes motor drivers, Bluetooth communication for remote control, and a microcontroller to manage all functions. The user-friendly mobile app interface facilitates easy adjustments of motor speeds, spin types, and shot angles, offering high flexibility for different training scenarios [3]. Jamaludin et al. further elaborate on an Arduino-based control system that manages the motors and movements, which is paired with a Bluetooth module for smartphone-based wireless control. This system leverages PWM control to fine-tune the speed and power supplied to the DC motors, enabling precise adjustments to the ball’s launch speed and travel distance [4]. Similarly, in the field of tennis ball machines, Gao’s research demonstrates the use of an STM32F407 microcontroller, which allows users to customize launch parameters such as speed, angle, and frequency, offering a highly responsive and versatile control experience [5].

\subsection{Actuators}

The selection and configuration of motors and actuators are crucial for controlling both the speed and spin of the balls in robotic launchers. AIMY utilizes high-performance brushless motors (T-MOTOR Antigravity MN5008 KV170) and servo motors to control the orientation and speed of the launch unit and ball feeding mechanism [1]. Similarly, in the table tennis robotic launcher described by Jamaludin et al., brushless motors are responsible for adjusting ball velocity and spin, while servo motors control the trajectory and launch angle to ensure precise delivery of balls during training sessions [2]. In the case of the mTTTbot, the launch unit operates with two brushless motors connected to silicone wheels, allowing for the generation of different types of spins, such as topspin, backspin, and sidespin, by adjusting the motor speeds [3]. Additionally, servo motors control the pitch, yaw, and roll axes of the launch head, providing precise adjustments for shot placement. According to Jamaludin et al., the robot uses DC motors to generate ball spin and adjust launch speed through Pulse Width Modulation (PWM) values, enabling fine-tuned control over ball travel distance [4]. Extending this approach to tennis ball machines, Gao’s research highlights the use of 12V DC motors that drive friction wheels with a concave design, enhancing ball grip and control over velocity and spin [5]. This combination of motors and actuators across different studies underlines their importance in achieving high precision and consistency in robotic launchers.

\vspace{1cm}In this state-of-the-art section, a comprehensive review of recent developments in table tennis ball launchers was conducted to inform the design of the project. In addition to that their advantages and disadvantages are discussed. Key mechanisms, including wheeled, pressurized, and hammered pitching systems, were analyzed to understand their respective strengths and limitations regarding speed, spin, and trajectory control. Ball feeding systems were explored to ensure continuous, jam-free ball supply for uninterrupted practice, while control units and actuator technologies were examined to enable precise adjustments and enhance the overall accuracy of ball delivery.  By studying these technologies, the most suitable components and designs for creating an efficient, adaptable, and realistic table tennis training system were identified. 

\section{Patents}
In this section, a review of existing patents related to table tennis ball launching machines is presented. This analysis aims to highlight innovative design approaches and technologies that were previously patented. By examining these patents, it is ensured that the design remains compliant with intellectual property laws while gaining insights into potential solutions that could inspire and guide the development of the project.
\subsection{Table Tennis Robot (US4765618A) \cite{Daley1988}}

\begin{minipage}{0.6\textwidth}  % Text takes 70% of the width
    This table tennis robot design aims to serve the ping-pong ball continuously at adjustable directions and methods, such as top-spin, back,and side-spins. This approach provides a more comfortable experience while practicing. The main idea here, which may be helpful, is that the balls are brought from bottom to top (from a lower level to a higher level), released to the serving mechanism and this procedure is continuously repeated. The serving mechanism consists of wheels to direct the balls. To accelerate the balls and satisfy the speed criteria, the design could be useful. However, on the other hand, depending on the elevation of the ball reservoir, the power consumption may be excessive and the design may be inconvenient. If the elevation is too high, the power needed to lift the balls could be quite high. To sum up, depending on the process and needs, this design could be beneficial and logical to implement.
\end{minipage}%
\hfill
\begin{minipage}{0.38\textwidth}  % Figure takes 28% of the width
    \centering
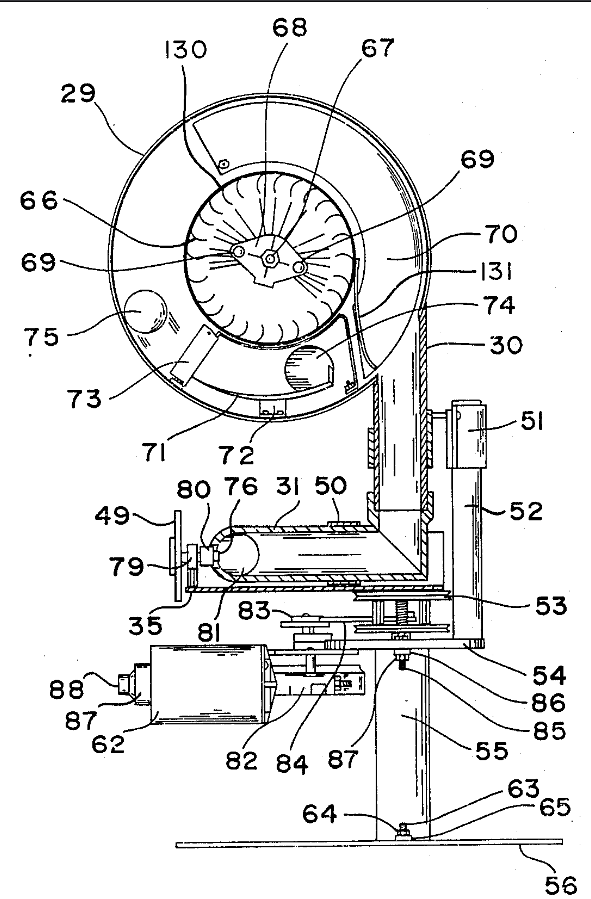
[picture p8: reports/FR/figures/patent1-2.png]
      % First image (48% width)
    \hfill
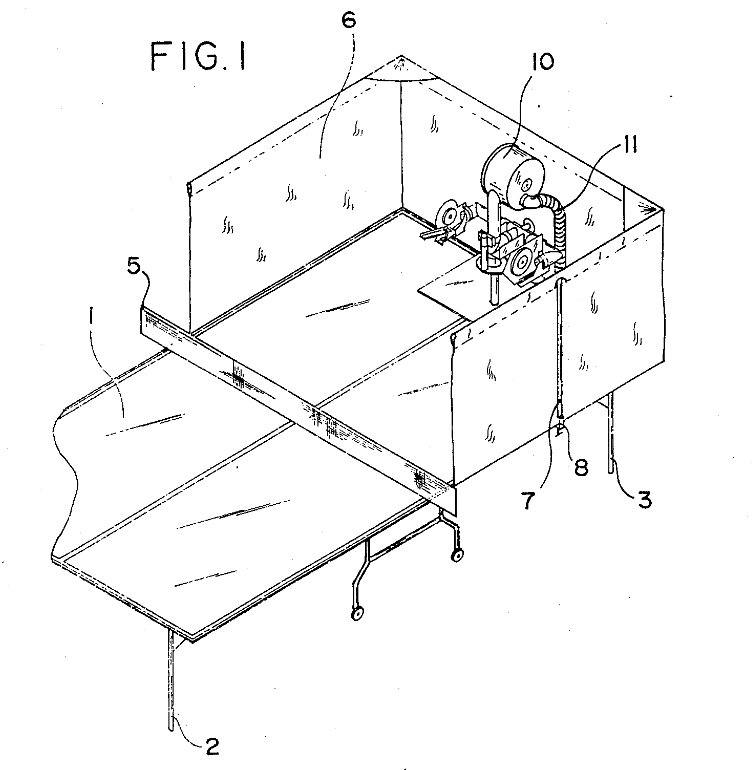
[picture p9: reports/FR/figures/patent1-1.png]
      % Second image (48% width)
    \captionof{figure}{General System Description \cite{Daley1988}}  % Caption for both images
    \label{fig:pt1-2}
\end{minipage}

\subsection{Table Tennis Serving Machine (US6604517B1) \cite{Chao2003}}

\begin{minipage}{0.7\textwidth}  % Text takes 70% of the width
    This design is a much simpler and more non-complex example of an approach while constructing a table tennis robot for those who would like to exercise and train by themselves. It basically consists of a gear system, ball reservoir segments capable of carrying 2 balls simultaneously, and a spring system to throw the ball. If the priority is simplicity, this design could be useful. Also, to achieve the desired speed, a stiff spring system could be useful. The main underlying reason that this design is patentable is that it replaces electronic components with mechanical components. Therefore, this design provides more simplicity. However, in terms of longevity, practicality, and ergonomics, this design is probably not the most usable one. The possible wear of the gear system may make the design unusable in a couple of years. In addition, the gear system could make the design heavy and difficult to carry.
\end{minipage}%
\hfill
\begin{minipage}{0.28\textwidth}  % Figure takes 28% of the width
    \centering
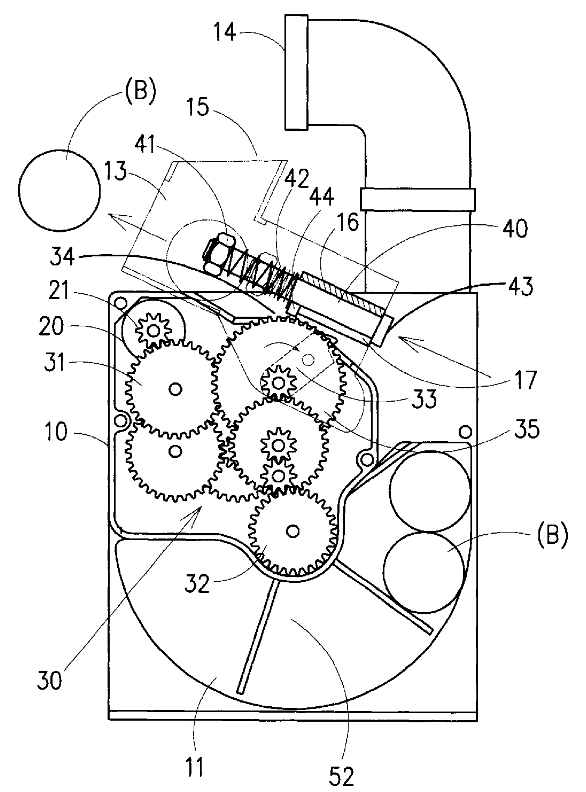
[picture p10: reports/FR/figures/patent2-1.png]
    
    \captionof{figure}{General schematic of serving machine \cite{Chao2003}}
    \label{fig:pt2-1}
\end{minipage}

\subsection{ Table Tennis Robot with Improved Serving Head Movement
 (EP3967376A1) \cite{Thoman2022}}

\begin{minipage}{0.7\textwidth}  % Text takes 70% of the width
     At that design, a ball feed collector can be seen. The main difference from the first design is that the internal pipe raises the balls to be able to throw them and this design raises the balls in a more effective way since the ball collector reservoir is lower, which could be a key point for a good design. There are several servo motors and gears to adjust the thrower part. To exemplify, the thrower is able to move upwards and downwards, depending on the process desired, which enables the practice to have a more realistic experience. Also, the thrower part is adjustable so that the ball can be manipulated to make a top-spin, back-spin, and side-spin type of throws. By the gear system, the angle of the thrower becomes adjustable. 
\end{minipage}%
\hfill
\begin{minipage}{0.28\textwidth}  % Figure takes 28% of the width
    \centering
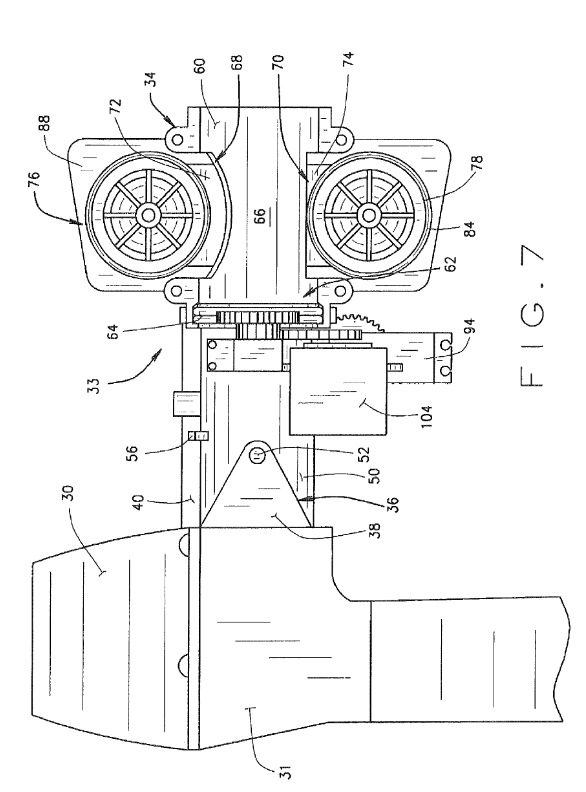
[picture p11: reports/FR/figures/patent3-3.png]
    
    \captionof{figure}{Side view and detailed mechanism of table tennis robot \cite{Thoman2022}}
    \label{fig:pt3-1}
\end{minipage}

\begin{figure}[H]
    \centering
    \begin{subfigure}{0.4\textwidth}
        \centering
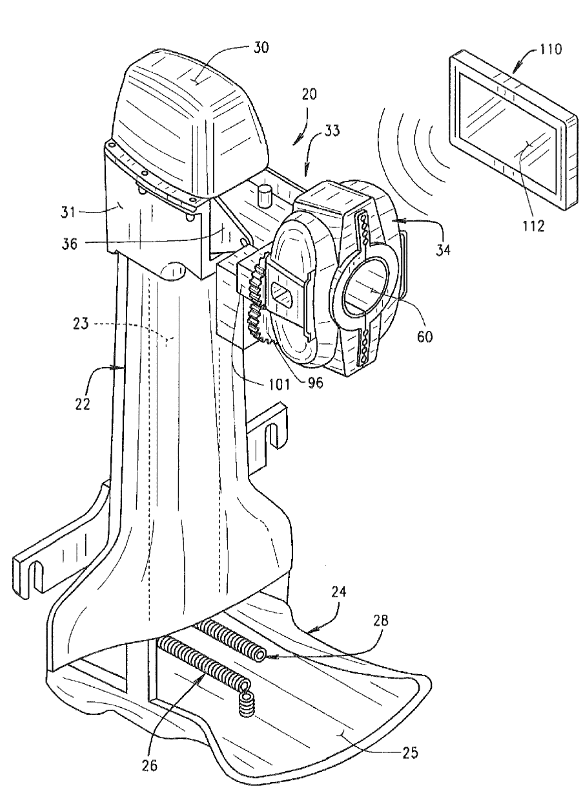
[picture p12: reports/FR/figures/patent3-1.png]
        
        \caption{Orthogonal view}
    \end{subfigure}
    \hfill
    \begin{subfigure}{0.4\textwidth}
        \centering
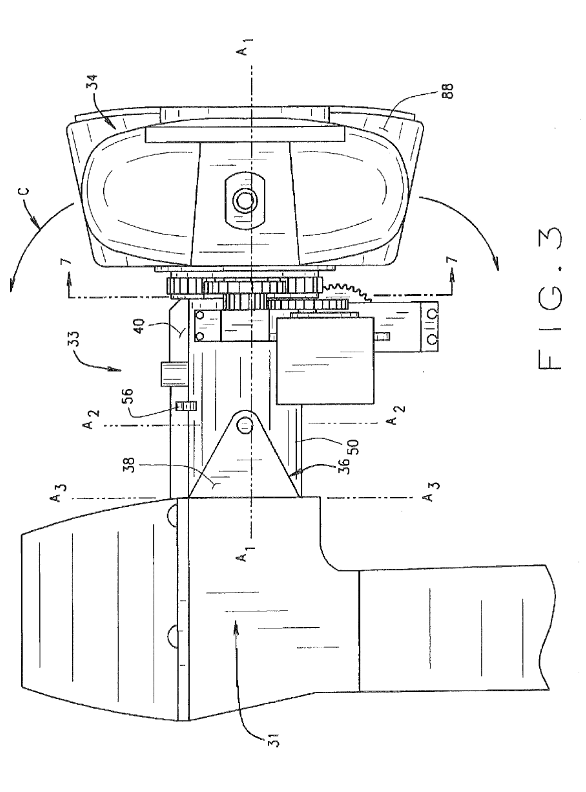
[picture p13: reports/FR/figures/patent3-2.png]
        
        \caption{General view}
    \end{subfigure}
    \caption{Orthogonal and general views of the table tennis robot \cite{Thoman2022}}
\label{fig:patetn3-2}
\end{figure}

\subsection{Programmable Ball Throwing Aparatus (US008287.4042B2) \cite{Romulo2012}}

\begin{minipage}{0.6\textwidth}  % Text takes 70% of the width
    In this device flight characteristics and field position parameters: spin, speed, ball trajectory are either programmed or manually selected by the user. The design is computer implemented and has built-in programs for different levels from beginner to expert. Also, it has specific modes for specific skill training like extreme backspin case. In addition, it allows users to program custom routines. The importance of this device for the project is that the planned product will also be adjustable for different flight parameters and trajectories. The underlying reason that this design is patentable comes from its programmability and freedom provided to the user.
\end{minipage}%
\hfill
\begin{minipage}{0.38\textwidth}  % Figure takes 28% of the width
    \centering
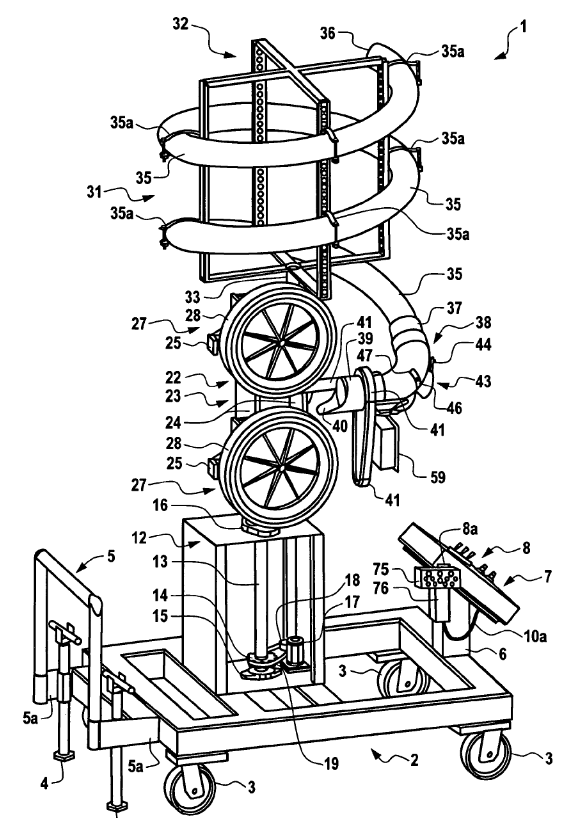
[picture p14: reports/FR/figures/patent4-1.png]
      % First image (48% width)
    \hfill
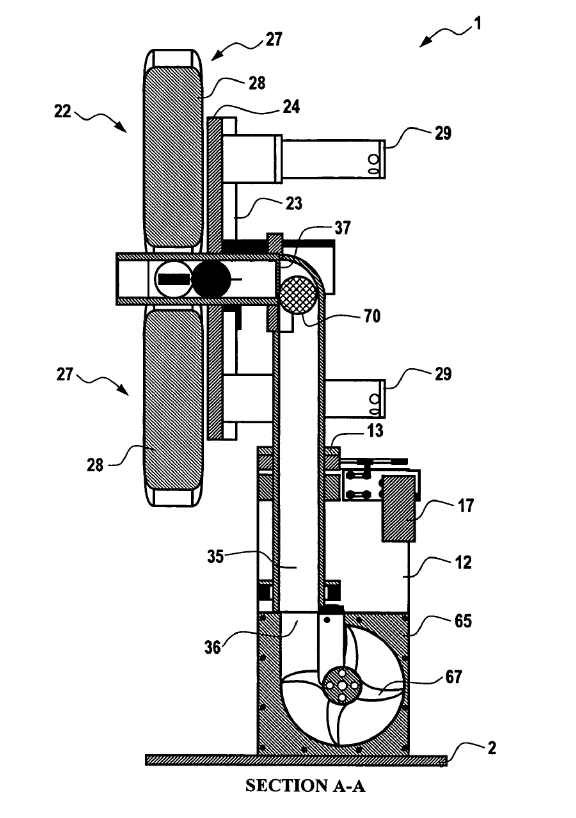
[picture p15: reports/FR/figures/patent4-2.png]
      % Second image (48% width)
    \captionof{figure}{General System Description \cite{Romulo2012}}  % Caption for both images
    \label{fig:patent4-1}
\end{minipage}

\subsection{Ball Throwing Device for Table Tennis (KR101992961B1) \cite{Kang2019}}

\begin{minipage}{0.6\textwidth}  % Text takes 70% of the width
    This patent describes a ball-throwing machine specifically designed for table tennis. The machine incorporates servomotors and various gears to control the ball's speed, spin, and direction. One key feature is its ability to continuously feed balls from a lower-level reservoir, reducing the machine's power consumption compared to designs with higher reservoirs. The ball thrower is adjustable for multiple spins (e.g., top-spin, back-spin), and the throwing mechanism is capable of providing angular adjustments for different ball trajectories. On the other hand, since the system can be constructed only once and it is not dispensable, this design may not meet the ergonomy criterion. 
\end{minipage}%
\hfill
\begin{minipage}{0.38\textwidth}  % Figure takes 28% of the width
    \centering
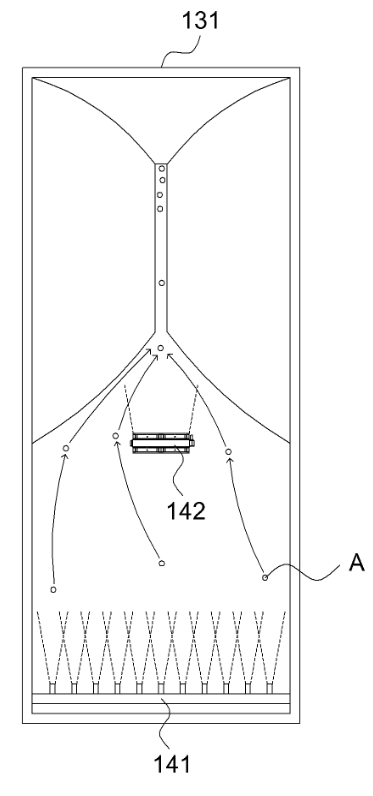
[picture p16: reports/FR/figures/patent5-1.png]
      % First image (48% width)
    \hfill
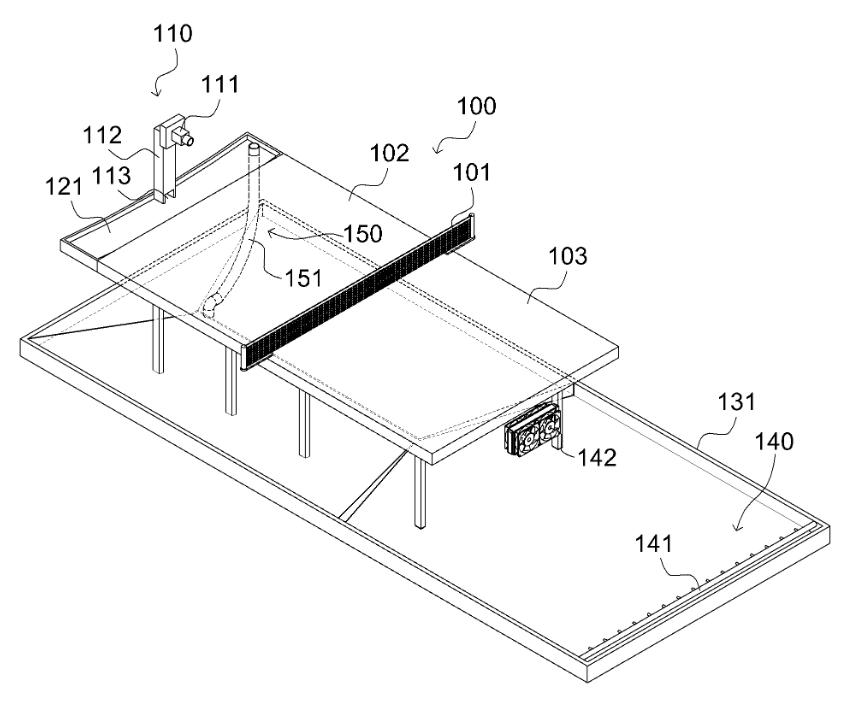
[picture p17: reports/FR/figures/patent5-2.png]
      % Second image (48% width)
    \captionof{figure}{Lower to Upper-Level Reservoir Feeding System \cite{Kang2019}}  % Caption for both images
    \label{fig:patent5-1}
\end{minipage}
\vspace{10pt}\\

The possible outcome of the research is, each of the designs has its advantages and disadvantages. The main idea is to be able to assess these designs wisely, get the ideas and inspiring points.

\section{Summary and Conclusion}
In this report, the results of a literature survey conducted spanning the commercial products in the market, state-of-the-art technologies and patents regarding the project at hand are presented. \\

A total of 10 commercial products are mentioned ranging from simple mechanical designs to highly advanced systems incorporating smart controls, whose different capabilities and aspects are studied to analyze their functions most useful to the project, and their shortcomings are discussed so as to how they could be improved upon, or be replaced with alternative solutions altogether. \\

State-of-the-art research made available many technologies and ideas that approach the technical problems encountered from different angles, and offer varying solutions to how the mechanisms operate. These different mechanisms are presented in detail to better understand their respective strengths and limitations regarding many technical aspects such as spin options, trajectory control, jam-free ball supply, enabling precise adjustments and accuracy. \\

A number of 5 patents are listed in this report, whose similarities and differences are discussed. Patents’ innovative approaches and methodologies to technical requirements including but not limited to power consumption, reserving and collecting the balls are mentioned to draw inspiration and compare the advantages and disadvantages of these designs. \\

In general, the information and ideas obtained from these research areas both gave rise to new inspiration and resulted in familiarizing with the many alternative solutions, while at the same time making apparent the need for a product to work upon the shortcomings and improve upon the strengths of the available designs to better simulate a real-life table tennis experience, thus enhancing the belief that this project will have a meaningful contribution to its field, and reinforcing the motivation to further work on it.

\newpage

\begin{sidewaystable}[h]
\centering
\scriptsize % Reduce font size
\begin{adjustbox}{width=\textwidth} % Scale the table to the text width
\begin{tabularx}{\textwidth}{|>{\centering\arraybackslash}X|>{\centering\arraybackslash}X|>{\centering\arraybackslash}X|>{\centering\arraybackslash}X|>{\centering\arraybackslash}X|>{\centering\arraybackslash}X|>{\centering\arraybackslash}X|>{\centering\arraybackslash}X|>{\centering\arraybackslash}X|>{\centering\arraybackslash}X|>{\centering\arraybackslash}X|}
\hline
\textbf{} & \textbf{PongBot Nova S Pro \cite{pongbotnova2024}} & \textbf{PowerPong Alpha \cite{powerpongalpha}} & \textbf{PowerPong Omega \cite{powerpongomega}} & \textbf{Huipang HP-07 \cite{huipanghp07}} & \textbf{Huipang S8-PRO \cite{huipangs8pro}} & \textbf{Huipang S1001 \cite{huipangs1001}} & \textbf{iPong V300 \cite{ipongv300}} & \textbf{Robo Pong Super Pro (3050) \cite{ipong2022}} & \textbf{Robo Pong Pro Digital (2055) \cite{robopong2055}} & \textbf{SIBOASI T899 \cite{siboasit899}} \\ \hline
\textbf{Price (USD)} & 350 & 1450 & 2195 & 256 & 763 & 172 & 140 & 2200 & 700 & 408 \\ \hline
\textbf{Length (cm)} & 46.5 & 24.1 & 24.1 & 39.4 & 88 & 41 & 28 & 28 & 28 & 165 \\ \hline
\textbf{Width (cm)} & 17.6 & 32.4 & 32.4 & 37.6 & 40 & 36 & 28 & 35.6 & 35.6 & 150 \\ \hline
\textbf{Height (cm)} & 34 & 78.7 & 78.7 & 35.8 & 41 & 32 & 48 & 83.8 & 83.8 & 78 \\ \hline
\textbf{Mass (kg)} & 4 & 10.89 & 10.89 & 4.42 & 7.5 & 4 & 1.25 & 8.15 & 10.9 & 5.4 \\ \hline
\textbf{Power (W)} & 24 & 24 & 24 & 36 & 50 & 36 & 50 & 50 & 50 & 60 \\ \hline
\textbf{Ball Frequency (balls per minute)} & 30-90 & 5-100 & 5-120 & 40-70 & 35-80 & 32-80 & up to 90 & 1-120 & 1-170 & 30-90 \\ \hline
\textbf{Ball Speed (m/s)} & 2-15 & 1-19 & 1-25 & 4-40 & 4-40 & 4-40 & 4-40 & 4-40 & 4-40 & 4-40 \\ \hline
\textbf{Capacity (balls)} & 200 & 100 & 100 & 120 & 200 & 120 & 100 & 120 & 120 & 80 \\ \hline
\textbf{No of spins} & 8 & 5 for topspin, 4 for backspin, 4 for right sidespin, 4 for left sidespin. & 7 for topspin, 5 for backspin, 6 for right sidespin, 6 for left sidespin. & 9 different spin options & 9 different spin options and no spin & 9 different spin options and no spin & 2 (Only Topspin and Backspin) & Topspin, Backspin, variety of side spins and no spin option & Topspin, Backspin, variety of side spins and no spin option & 4 \\ \hline
\textbf{Type of controller} & Mobile app + wireless remote controller & Control box and connects with a thin, light cable & No control box / Tablet or phone app can be used & Wired control box & Wireless remote & Wired control box & Wireless remote + digital panel & Mobile Application/Bluetooth & Digital Control box & Remote control \\ \hline
\textbf{Catch net to recycle balls} & - & + & + & - & + & - & - & + & + & + \\ \hline
\textbf{Material} & German BASF materials & Rubber + Metal & Rubber + Metal & Acrylonitrite butadiene styrene & Plastic + Metal & Plastic + Metal & Metal & Plastic + Metal & Plastic + Metal & Plastic + Metal \\ \hline
\textbf{Features} & \begin{itemize}[noitemsep, left=0pt, align=left]
    \tiny
    \item 20 to 30 up and down trajectory control
    \item Can be placed at 9 different positions on table
    \item Customizable spin, frequency, speed, oscillation, and trajectory settings
    \item Trajectory visualization on app
\end{itemize} & \begin{itemize}[noitemsep, left=0pt, align=left]
    \tiny
    \item 3 motors 120° degrees separated
    \item Allows many different shot types
    \item Has memory slots for shots
    \item Automatic Frequency Control
\end{itemize} & \begin{itemize}[noitemsep, left=0pt, align=left]
    \tiny
    \item 3 motors 120° degrees separated
    \item Allows many different shot types
    \item Unlimited memory for shots
    \item Individual Frequency Control
    \item Delay/Break time
\end{itemize} & \begin{itemize}[noitemsep, left=0pt, align=left]
    \tiny
    \item Rotating head for different spin directions
    \item 3 modes for trajectory angle
    \item Includes special Huipang balls reduce friction 
\end{itemize} & \begin{itemize}[noitemsep, left=0pt, align=left]
    \tiny
    \item Rotating head for different spin directions
    \item Adjustable head for trajectory angle
    \item Includes special Huipang balls reduce friction 
    \item Preset long/short ball, serve style practice
\end{itemize} & \begin{itemize}[noitemsep, left=0pt, align=left]
    \tiny
    \item Double heads for different types of serves
    \item Includes special Huipang balls reduce friction 
    \item Can serve two balls simultaneously
    \item 3 head modes for trajectory angle
\end{itemize} & \begin{itemize}[noitemsep, left=0pt, align=left]
    \tiny
    \item Includes tilt stand to change ball trajectory
    \item Can stand on its own
    \item Easily transportable
\end{itemize} & \begin{itemize}[noitemsep, left=0pt, align=left]
    \tiny
    \item Rotating head for different spin directions
    \item Different difficulty levels (Beginner to advanced)
    \item Advanced launching options
    \item Indicator lights that’s shows spin force and direction
\end{itemize} & \begin{itemize}[noitemsep, left=0pt, align=left]
    \tiny
    \item Rotating head for different spin directions
    \item Manually adjustable vertical tilt angle
    \item Different difficulty levels (Beginner to advanced)
\end{itemize} & \begin{itemize}[noitemsep, left=0pt, align=left]
    \tiny
    \item Rotating head for different spin directions
    \item Suitable for middle line ball, forehand ball, backhand ball trainings
\end{itemize}\\ \hline
\end{tabularx}
\end{adjustbox}
\caption{Comparison of Table Tennis Robots}
\label{commercial}
\end{sidewaystable}

% Prevent floats from passing this point
\FloatBarrier

\chapter{Project Planning and Management}
\addcontentsline{toc}{chapter}{Project Planning and Management}
\setcounter{section}{0}
\renewcommand*{\theHsection}{chX.\the\value{section}}

% Start of sections

\section{Introduction}
This report presents the planning and organization for the management of the Table Tennis Ball Pitcher Machine project. A structured timetable is established to guide each project phase, from problem definition to testing, ensuring efficient workflow. This document details the planning approach, task distribution and timeline established to ensure systematic project execution. The project members responsible for the tasks are abbreviated as in Table \ref{tab:teammembere}.

\begin{table}[h!]
\centering
\begin{minipage}{0.45\textwidth}
    \centering
    \begin{tabular}{|c|c|}
    \hline
    \textbf{Name} & \textbf{Abbreviation}\\
    \hline
    Abdullah Can Seyhanlı &  ACS\\
    Altay Ata Ateş & AAA\\
    Arman Utku Aydın & AUA\\
    Abdullah Salih Taşdelen &  AST\\
    \hline
    \end{tabular}

\end{minipage}%
\hfill
\begin{minipage}{0.45\textwidth}
    \centering
    \begin{tabular}{|c|c|}
    \hline
    \textbf{Name} & \textbf{Abbreviation} \\
    \hline
    Bilal Açıksöz & BA\\
    Kutay Can Yapıcı & KCY\\
    Ömer Aslan & ÖA\\
    Özge Dilan Tuna & ÖDT\\
    Yunus Emre Özçelik & YEÖ\\
    \hline
    \end{tabular}    
\end{minipage}
    \caption{The Members of the Project}
    \label{tab:teammembere}
\end{table}

\section{Organization of the Project}

In this section of the report, the definition of tasks and the workload distribution among the team members are presented. As a first step, a literature survey is conducted to define the problem. After defining the problem project requirements and specifications are determined. In consideration of these steps, the functions of the project are decomposed. 

\subsection{Explanation of the Tasks and Their Definitions}

\subsubsection{Literature Survey}
At the start of a project, literature survey carries great importance so as to gather information about the related products and technologies available on the market. Also, research regarding the patents related to the project is conducted. Ultimately, the literature survey gives insight about the direction the project will take. \\

\paragraphs{\textbf{a. Commercial Product Research (AAA, AUA, BA})}
This section involves the research of the products on the market. Prices of these products, their design criteria and to what extent they satisfy the said criteria are evaluated. Studying the interest on the market regarding the field and products also contributes to the project. \\

\paragraphs{\textbf{b. State of the Art Research on Related Projects (ÖDT, AST, KCY)}}
In this part, scientific papers and technological advancements that are related to the project are researched. State of the art research, unlike the commercial product part, takes into consideration the technologies that are new and some cutting-edge, thereby allowing for more creative ideas and open-minded thinking. \\

\paragraphs{\textbf{c. Patent Research (ACS, YEÖ, ÖA)}}
Patent research is a very crucial step in a design process. A product created without researching and knowing the patented products related to the project beforehand is not viable. The components and the products similar to the design in mind must be determined.  

\subsubsection{Project Initiation}
The project needs to be initialized and worked over after the literature survey is completed. An investigation process should be completed by using a step-by-step approach. After all the steps are completed, the project is to be completely initiated. \\

\paragraphs{\textbf{a. Problem Definition (AAA, YEÖ)}}
A problem needs to be defined properly if a design is to be made as a solution. Determining the problem correctly and thoroughly is important and makes it easier to create a good design in the later stages of the process. \\

\paragraphs{\textbf{b. Project Requirements (ÖDT, KCY, ÖA)}}
 In this step the requirements that should be met and the functions the product must be able to perform are defined without giving the numerical constraints or any measurable limitations. \\
 
\paragraphs{\textbf{c. Design Specifications (BA, AUA)}}
The requirements specified on the previous step are defined numerically in this step. Functions the product must be able to perform and the restrictions it is subjected to are indicated in a quantitative way. \\

\paragraphs{\textbf{d. Design Criteria (ACS, AST)}}
In this step, the design criteria for the product should be stated, and the percent weight of importance for each of the criteria are assigned. 

\subsubsection{Functional Decomposition}
Functional decomposition is a process to separate an engineering solution/device into its subfunctions. It is created based on need statements which is the process of converting customer needs into solution neutral engineering actions. Each subfunction should be suitable for individual examination. After the functional decomposition is performed, each function is investigated to find suitable solutions. \\

\paragraphs{\textbf{a. Flow Chart (YEÖ, BA)}}
Flow chart is a type of functional chart which includes all the subfunctions from the main function to the subfunction in a logical or temporal order with material, information, and energy inputs. These subfunctions are grouped by considering a common function to be performed. For the given inputs the outputs are also determined, considering the conservation. \\

\paragraphs{\textbf{b. Function Tree Chart (YEÖ, AST, AAA)}}
Functional tree chat is another type of functional decomposition. Main difference from the flow chart is that function tree is designed with levels starting from the main function extending with relevant subfunctions till the solution of each subfunction. \\

\subsubsection{Project Planning}
It is crucial to plan the schedule the project properly. Insufficient planning may lead to many problems, such as production errors and delays of the reports. To be able to plan properly, it is important to know the members of the group well and assign them tasks according to their interests and knowledge areas. \\

\paragraphs{\textbf{a. Project Organization (ALL TEAM)}}
Project Organization as a task involves setting up the structure, roles, and processes necessary for a project to run efficiently and achieve its objectives. Project Organization is foundational to project success, as it sets up the necessary framework, team alignment, and resources to achieve project goals. \\

\paragraphs{\textbf{b. Task Explanation and Assignment (AUA)}}
At the start of a project, first step is to determine the tasks. The task definitions must be done clearly and in a way that fully encompasses what the task should achieve. So, it is easier to determine how to approach each task, and it is possible to assign them to the member that is most capable of undertaking it. \\

\paragraphs{\textbf{c. Timetable and Timeline Creation (AUA, AST)}}
Aside from assigning the tasks and setting their definitions, it is important to allocate the time to complete these tasks. To achieve it, a timetable should be constructed and it has to be ensured that it is followed properly. For the timeline, it is necessary to fill a Gantt chart with the durations decided at the timetable, including the specific dates. 

\subsubsection{Conceptual Design}
Conceptual design is mainly composed of two steps: concept generation and concept evaluation. \\

\paragraphs{\textbf{a. Morphological Chart (ALL TEAM)}}
Morphological chart is a chart where generated concepts that are considered to be logical solutions at first look are listed. It is a method for concept generation. This process is done for each sub-function obtained during the functional decomposition and listed in the morphological chart. Generated concepts are illustrated with sketches which are in conceptual level, not necessarily in the engineering level. All the concepts must be in the same level and should perform the function for sure. \\

\paragraphs{\textbf{b. Concept Evaluation (ALL TEAM)}}
At this step, the generated concepts which are listed in morphological chart are evaluated considering each engineering criteria, choosing from several types of evaluation methods. The concepts are then graded. The results obtained from this step determines the optimal solution/s for each sub-function.

\subsubsection{Detailed Design}
At this step, the process which have been theoretical up to this point and the generated concepts take its final shape and the product architecture is determined. All the design parameters are quantified and parts that will perform the functions take form. This step is highly iterative and requires good communication among the team. \\

\paragraphs{\textbf{a. Kinematic Design (YEÖ, ACS)}}
This process includes kinematic analysis, synthesis, and optimization for all parts and parameters of the system. It requires hand calculations and geometry-based software. \\

\paragraphs{\textbf{b. Static Analysis (YEÖ, AAA)}}
 This process includes structural analysis which includes material selection and stress analysis of the parts. It requires hand calculations and engineering software. \\
 
\paragraphs{\textbf{c. Geometric Analysis (AUA, BA)}} 
This process includes CAD modeling, and geometrical parameter determination. \\

\paragraphs{\textbf{d. Circuit Design (AST)}}
In this process the circuitry needed for the motor control, buttons, encoders etc. and also the voltage regulators will be designed. It is crucial for not harming any electrical/mechanical components.

\subsubsection{Manufacturing}
\paragraphs{\textbf{a. Procurement (AUA, AST)}}
After the analyses are complete, the materials chosen according to the market research conducted previously are to be supplied. Procuring the materials is a crucial part since manufacturing process cannot start without deciding on and obtaining the materials needed. \\

\paragraphs{\textbf{b. Determination of Manufacturing Methods (YEÖ, KCY)}}
Regarding the project requirements, design specifications and the materials, the suitable methods to manufacture the system are to be decided on. In this part, the priority is to provide the sustainability of the material life and to avoid possible excessive expenses.  \\

\paragraphs{\textbf{c. Producing the Parts (AAA, ÖA, BA)}}
The necessary parts are to be produced by applying the manufacturing methods determined at the previous part.  \\
 
\paragraphs{\textbf{d. Assembly (ACS, ÖDT)}}
In the assembly section, the produced parts are to be joined together to create the final product. \\

\paragraphs{\textbf{e. Quality Control (AST, AUA)}}

Quality control should be performed for each part produced to ensure the quality of the materials, make sure the standards are met, foresee the potential unexpected changes and deviations to avoid them as much as possible, and to increase the efficiency of the process. After the assembly is done, it is important to do a final quality control to obtain an overall result. 

\subsubsection{Documentation}

\paragraphs{\textbf{a. Reports (ALL TEAM)}}
From the beginning of the project, reports are to be written to record the project design procedure and explain the steps better. This part also makes it easier to plan the timeline and organize the time until the deadline. \\

\paragraphs{\textbf{b. Drawings (KCY, YEÖ, AUA)}}
It is important to have the drawings of each part of the system, which includes the tolerances, dimensions and constraints, in order to manufacture the parts designed. \\

\paragraphs{\textbf{c. Calculations (AST, ACS, ÖA)}}
The pre-design calculations should be included for speed, motion, power, space required and trajectory motion etc. to demonstrate that the solutions are viable for the project requirements. 
\newpage

% Repeat for each task (e.g., Detailed Design, Manufacturing, Documentation)

\subsection{Time Table}

\begin{table}[h!]
\centering
\begin{minipage}{0.45\textwidth}
    \centering
    \scriptsize
    \begin{tabular}{|c|c|c|}
    \hline
    \textbf{Task ID} & \textbf{Duration} & \textbf{Team Members} \\
    \hline
    1.a & 2 weeks & AAA, AUA, BA \\
    1.b & 2 weeks & ÖDT, AST, KCY \\
    1.c & 2 weeks & ACS, ÖA, YEÖ \\
    2.a & 1 week & AAA, YEÖ \\
    2.b & 1 week & ÖDT, KCY, ÖA \\
    2.c & 1 week & BA, AUA \\
    2.d & 1 week & ACS, AST \\
    3.a & 1 week & YEÖ, BA \\
    3.b & 2 weeks & YEÖ, AST, AAA \\
    4.a & 1 week & ALL TEAM \\
    4.b & 1 week & AUA \\
    4.c & 1 week & AUA, AST \\
    5.a & 2 weeks & ALL TEAM \\
    \hline
    \end{tabular}
\end{minipage}%
\hfill
\begin{minipage}{0.45\textwidth}
    \centering
    \scriptsize
    \begin{tabular}{|c|c|c|}
    \hline
    \textbf{Task ID} & \textbf{Duration} & \textbf{Team Members} \\
    \hline
    5.b & 1 week & ALL TEAM \\
    6.a & 2 weeks & YEÖ, ACS \\
    6.b & 2 weeks & YEÖ, AAA \\
    6.c & 2 weeks & AUA, BA \\
    6.d & 1 week & AST \\
    7.a & 2 weeks & AUA, AST \\
    7.b & 1 week & YEÖ, KCY \\
    7.c & 3 weeks & AAA, ÖA, BA \\
    7.d & 1 week & ACS, ÖDT \\
    7.e & 1 week & AST, AUA \\
    8.a & 6 weeks & ALL TEAM \\
    8.b & 2 weeks & KCY, YEÖ, AUA \\
    8.c & 2 weeks & AST, ACS, ÖA \\
    \hline
    \end{tabular}
\end{minipage}
    \caption{Time table showing workload distribution}
\end{table}

\subsection{Timeline}
The Gannt Chart is in Appendix, Fig. \ref{fig:gannt}.

\section{Summary and Conclusion}
In this report, planning and organization of the project is documented. It is of upmost importance that the fundamentals of the project is laid out clearly so as to ensure the project proceeds smoothly and with minimal obstacles, so the initial research and concept design parts are crucial. Accumulation of ideas and different concepts allow for a wide range of solutions to possible problems or discrepancies that might arise during the process. Another important step is to manage the team members and their tasks. For an effective and efficient project process, the communication and concord between team members, as well as assigning their undertakings according to their individual capabilities and strength is very important.
For the evaluation and conceptual design steps, software like Microsoft Excel are to be used for the organization of the criteria and concepts. For the detailed design further into the project, CAD software will be useful for the technical drawings, and the analysis parts will be carried out using analysis software tools. For the manufacturing part, CAM software is helpful to determine the methods of manufacturing, which will then be performed in machine shops, using various tools and methods depending on the part and material, such as additive manufacturing, turning/milling and even CNC machining.

% Prevent floats from passing this point
\FloatBarrier

% % References section
% \bibliographystyle{IEEEtran} % or any style you prefer
% \bibliography{bibliography}

% Yatay mi yapsak??
\begin{figure}
    \centering
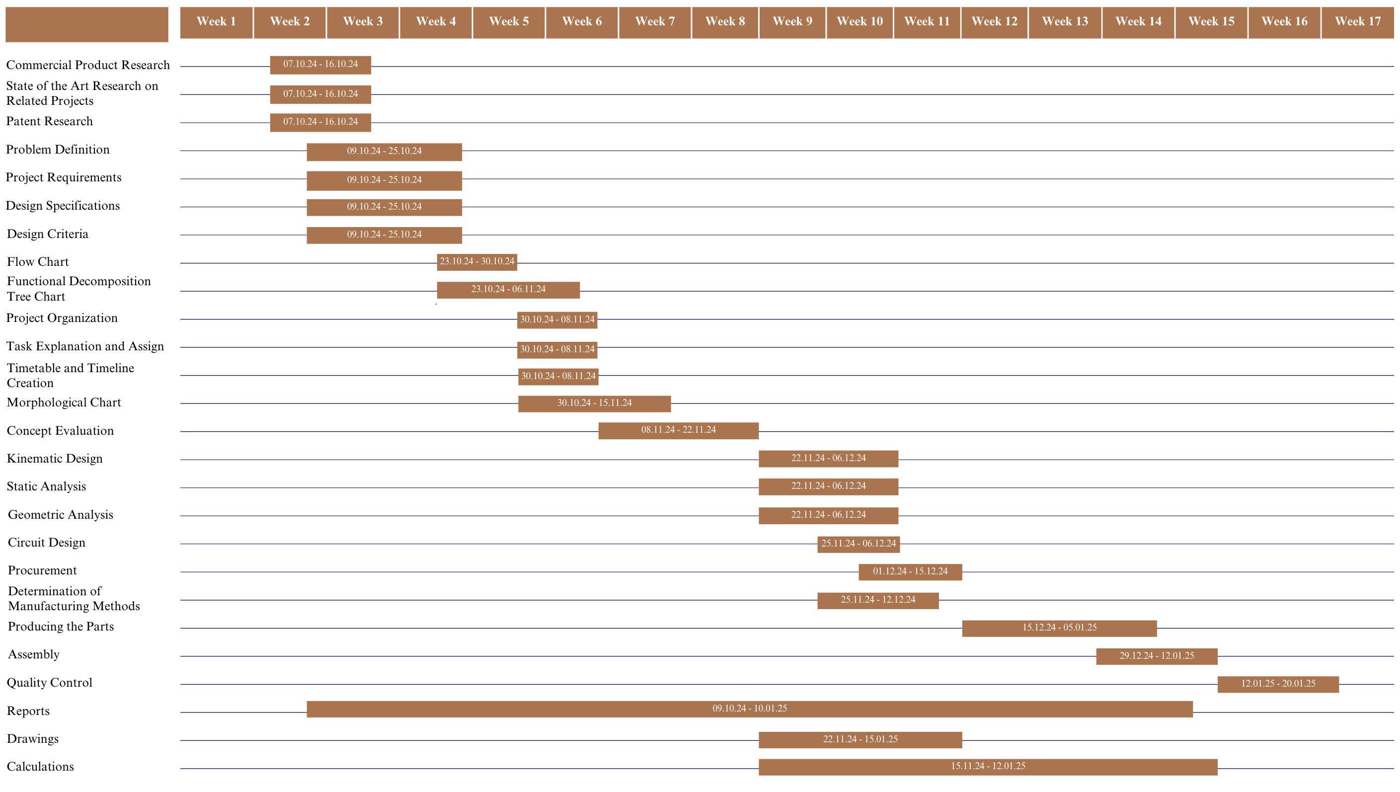
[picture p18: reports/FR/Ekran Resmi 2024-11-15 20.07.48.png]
    
    \caption{Gantt Chart}
    \label{fig:gannt}
\end{figure}

\chapter{Conceptual Design}

\section{Introduction}

This report presents and details the conceptual design part for the project of a Table Tennis Ball Pitcher Machine. By guide of the functional decomposition chart, project requirements and design criteria, and using the function alternatives developed in the morphological chart, different concepts are generated. These concepts are then evaluated in order by the evaluation criteria, and the best concept is chosen to meet the requirements and carry out all functions in the most efficient and effective way.

\section{Concept Development and Presentation}

Concept development and presentation are about turning ideas into clear plans and sharing them effectively. Concept development involves brainstorming, researching, and improving ideas to make them practical. Presentation is about explaining these ideas clearly using stories, visuals, and persuasive communication. Together, they help bring creative ideas to life and make them useful and understandable.

The list form and chart form of the functional decomposition we created during the concept development phase are given below (Fig. \ref{fig:fd}).

\begin{itemize}
    \item Launching the Balls to Desired Places
    \begin{itemize}
        \item Throwing the balls with a desired spin:
        \begin{itemize}
            \item Giving spin to the ball
            \item Controlling the spin
        \end{itemize}
        \item Throwing the balls with a desired speed:
        \begin{itemize}
            \item Giving speed to the ball
            \item Controlling the speed
        \end{itemize}
        \item Throwing the balls with a desired yaw angle:
        \begin{itemize}
            \item Giving yaw angle to the launching mechanism
            \item Controlling the yaw angle
        \end{itemize}
        \item Throwing the balls with a desired pitch angle:
        \begin{itemize}
            \item Giving pitch angle to the launching mechanism
            \item Controlling the pitch angle
        \end{itemize}
    \end{itemize}

    \item Accepting User Inputs
    \begin{itemize}
        \item Accepting frequency information from the user
        \item Accepting trajectory information from the user
        \item Accepting numerical information from the user
        \item Allowing user to position the device
    \end{itemize}

    \item Managing the Supply of the Balls
    \begin{itemize}
        \item Preventing balls from escaping
        \item Storing the balls
        \item Feeding the balls from storage:
        \begin{itemize}
            \item Transferring the balls from storage
            \item Controlling the ball feed from storage
        \end{itemize}
        \item Feeding to launching:
        \begin{itemize}
            \item Transferring the balls to launch
            \item Controlling the ball feed for launching
        \end{itemize}
        \item Managing the frequency of the ball supply:
        \begin{itemize}
            \item Giving the balls the desired frequency
            \item Controlling the ball frequency
        \end{itemize}
    \end{itemize}
\end{itemize}

\begin{figure}[H]
    \centering
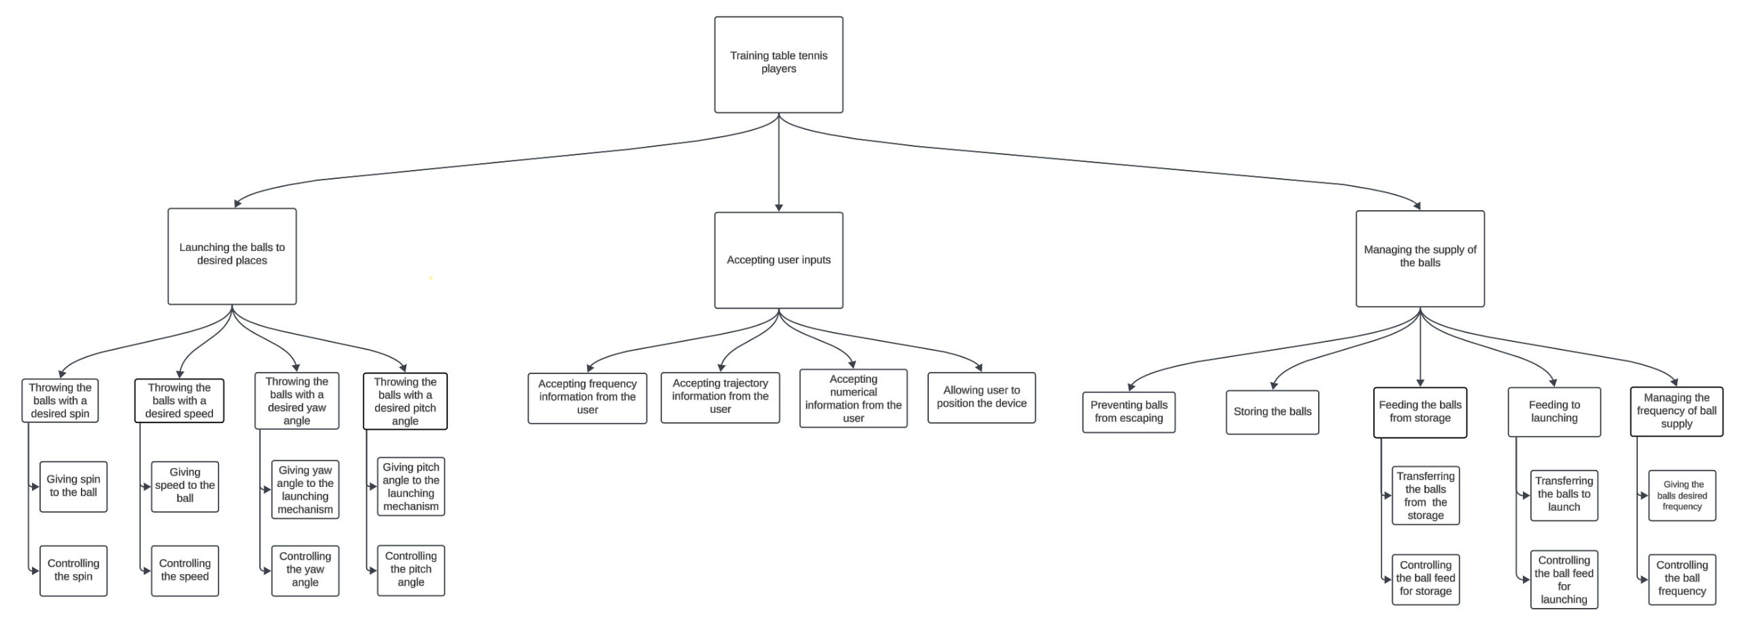
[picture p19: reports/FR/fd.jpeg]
    
    \caption{Functional Decomposition}
    \label{fig:fd}
\end{figure}

The morphological chart containing the solutions of the functions included in functional decomposition is located in the Appendix \ref{app:morpho}. \\

The detailed explanation of each concepts are given below: \\

    \textbf{Concept 1:}
    
    The balls are to be stored by using a groove mechanism (as shown in Figure ~\ref{fig:groove_mechanism}) while providing recyclability of the balls with a net (Figure ~\ref{fig:net} ). Then the balls are transferred from the storage by a vertical spiral mechanism (Figure ~\ref{fig:spiral}) dictated with a stepper motor. A rotating pusher (Figure ~\ref{fig:rotating_pusher}) at the end of the vertical spiral mechanism is used to direct the balls coming from the spiral to the launching mechanism with desired frequency. The 3 wheel mechanism (Figure ~\ref{fig:3wheel}), which is controlled by DC motors is benefitted to give and control the spin options and speed of the balls. The yaw angle value is controlled by using gears (Figure ~\ref{fig:gear1}), which rotates the head. The pitch angle is controlled by a four bar mechanism (Figure ~\ref{fig:fourbar}). Both controlling mechanisms are connected with servo motors to rotate the head in the desired directions. The trajectory and frequency information are accepted from the user with an integrated controller (Figure ~\ref{fig:integrated}). Accepting numerical information from the user is provided by using a potentiometer with buttons (Figure ~\ref{fig:pot}). Finally, the user is allowed to fix the device to the table by using clamps (Figure ~\ref{fig:clamp}). \\

    \textbf{Concept 2:}
    
    The balls are to be stored by using a box (Figure ~\ref{fig:box}), while providing recyclability of the balls with a net (Figure ~\ref{fig:net}). Then the balls are transferred from the storage to the launcher by a translating box (Figure ~\ref{fig:translating_box}) with a stepper motor. The balls are transferred to launch by the effect of gravity (represented at Figure ~\ref{fig:gravity}), while the desired frequency is provided by a rotating hole (Figure ~\ref{fig:rotating_hole}). The orientation of the hole determines the frequency. The 4 wheel mechanism (Figure ~\ref{fig:4wheel}), which is controlled by BLDC motors is benefitted to give and control the spin options and speed of the balls. The yaw angle values are controlled by using four bar mechanisms (Figure ~\ref{fig:fourbar_yaw}), and pitch angle values are controlled by a rope controlled head pulley (Figure ~\ref{fig:rope})  to rotate the head in the desired directions. Both mechanisms are dictated by servomotors. The trajectory and frequency information are accepted from the user with an integrated controller (Figure ~\ref{fig:integrated}). Accepting numerical information from the user is provided by using a potentiometer with buttons (~\ref{fig:pot}). Finally, the user is allowed to fix the device to the table by using clamps (Figure ~\ref{fig:clamp}). \\

    \textbf{Concept 3:}

    The balls are to be stored by using a box (Figure ~\ref{fig:box}) while providing recyclability of the balls with a net (Figure ~\ref{fig:net}). Then the balls are transferred from the storage to the launcher by a vertical spiral mechanism (shown at Figure ~\ref{fig:spiral}) dictated with a stepper motor. A rotating pusher (Figure ~\ref{fig:rotating_pusher}) at the end of the vertical spiral mechanism is used to direct the balls coming from the spiral to the launching mechanism and give the desired launch frequency. The 2 wheel mechanism (Figure ~\ref{fig:2wheel}), which is controlled by DC motors is benefitted to give and control the spin options and speed of the balls. The control of yaw and pitch angle is provided by bevel gear mechanisms (Figures ~\ref{fig:bevel} and ~\ref{fig:bevel_yaw}). Both controlling mechanisms are connected with servo motors to rotate the head in the desired directions. The trajectory and frequency information are accepted from the user with a wired remote (Figure ~\ref{fig:wired}). Accepting numerical information from the user is provided by using a potentiometer with buttons (Figure ~\ref{fig:pot}). Finally, the user is allowed to fix the device to the table by using a clamp mechanism (Figure ~\ref{fig:clamp}). \\

    \textbf{Concept 4:}

    The balls are to be stored by using a groove mechanism (Figure ~\ref{fig:groove_mechanism}) while providing recyclability of the balls with a net (Figure ~\ref{fig:net}). Then the balls are transferred from the storage to the launcher by a maltese wheel mechanism (Figure ~\ref{fig:maltese}) dictated with a stepper motor. Also, this maltese wheel is used to direct the balls to the launching mechanism by the pushing effect of the consecutive balls and helps give the desired frequency. The 3 wheel mechanism (Figure ~\ref{fig:3wheel}), which is controlled by BLDC motors is benefitted to give and control the spin options and speed of the balls. The control of yaw and pitch angle values are done by gear mechanisms (Figures ~\ref{fig:gear} and ~\ref{fig:gear2}), which are connected with servo motors. The gears control the pitch and yaw angle values by rotating the head and base, respectively. The trajectory and frequency information are accepted from the user with an integrated controller (Figure ~\ref{fig:integrated}). Accepting numerical information from the user is provided by using a potentiometer with buttons (Figure ~\ref{fig:pot}). Finally, the user is allowed to fix the device to the table by using clamps (Figure ~\ref{fig:clamp}). \\

    \textbf{Concept 5:}

    The balls are to be stored by using a tunnel mechanism (Figure ~\ref{fig:tunnel_mechanism}) while providing recyclability of the balls with a net (Figure ~\ref{fig:net}). This tunnel is placed between a maltese wheel (Figure ~\ref{fig:maltese}) on bottom and a slider crank (Figure ~\ref{fig:slider_crank}) at top, the maltese wheel enables the ball entrance to the tunnel from the net, whereas the slider crank transfers balls to the launching with desired frequency. These maltese wheels are activated with stepper motors. The 2 tension belt with spinning head mechanism (Figure ~\ref{fig:2tension}), which is controlled by BLDC motors is benefitted to give and control the spin options and speed of the balls. The control of pitch angle is provided by a worm gear mechanism (Figure ~\ref{fig:worm}) and the yaw angle is controlled by a gear mechanism (Figure ~\ref{fig:gear2}), rotating the head from the base. Both controlling mechanisms are connected with servo motors to rotate the head in the desired directions. The trajectory and frequency information are accepted from the user with an integrated controller (Figure ~\ref{fig:integrated}). Accepting numerical information from the user is provided by using an encoder (Figure ~\ref{fig:encoder}) . Finally, the user is allowed to fix the device to the table by using clamps (Figure ~\ref{fig:clamp}). \\

    \textbf{Concept 6:}

    The balls are to be stored by using a groove mechanism (Figure ~\ref{fig:groove_mechanism}) while providing recyclability of the balls with a net (Figure ~\ref{fig:net}). A maltese wheel (Figure ~\ref{fig:maltese}) is benefitted to raise the balls to a selected elevation and the transferring process from the storage is initiated. Then the balls are transferred to the launcher by the effect of gravity (represented at Figure ~\ref{fig:gravity}) . The desired frequency is given by the movement of a lid mechanism (Figure ~\ref{fig:lid_mechanism}). The 3 wheel mechanism (Figure ~\ref{fig:3wheel}) , which is controlled by DC motors is benefitted to give and control the spin options and speed of the balls. The control of yaw and the pitch angle is controlled by four bar mechanisms (Figures ~\ref{fig:fourbar_yaw} and ~\ref{fig:fourbar}). Both controlling mechanisms are connected with servo motors to rotate the head in the desired directions. The trajectory and frequency information are accepted from the user with an integrated controller (Figure ~\ref{fig:integrated}). Accepting numerical information from the user is provided by using a potentiometer with buttons (Figure ~\ref{fig:pot}). Finally, the user is allowed to fix the device to the table by using clamps (Figure ~\ref{fig:clamp}). \\

    \textbf{Concept 7:}

    The balls are to be stored by using a groove mechanism (Figure ~\ref{fig:groove_mechanism}) while providing recyclability of the balls with a net (Figure ~\ref{fig:net}). Then the balls are transferred from the storage to the launcher by a belt mechanism (Figure ~\ref{fig:belt}) dictated with a stepper motor. A maltese wheel (Figure ~\ref{fig:maltese_wheel} ) mechanism is used to direct the balls coming from the vertical belt to the launching mechanism, also the desired frequency is given. The 2 wheel mechanism (Figure ~\ref{fig:2wheel}), which is controlled by BLDC motors is benefitted to give and control the spin options and speed of the balls. The pitch angle value is controlled by using bevel gear (Figure ~\ref{fig:bevel}), and yaw angle value is controlled by a worm gear (Figure ~\ref{fig:worm_yaw}). Both controlling mechanisms are connected with servo motors to rotate the head in the desired directions. The trajectory and frequency information are accepted from the user with an integrated controller (Figure ~\ref{fig:integrated}). Accepting numerical information from the user is provided by using a potentiometer with buttons (Figure ~\ref{fig:pot}). Finally, the user is allowed to fix the device to the table by using clamps (Figure ~\ref{fig:clamp} ). \\

    \textbf{Concept 8:}

    The balls are to be stored by using a groove mechanism (Figure ~\ref{fig:groove_mechanism}) while providing recyclability of the balls with a net (Figure ~\ref{fig:net}). Then the balls are transferred from the storage to a vertical tube by a maltese wheel (Figure ~\ref{fig:maltese}) dictated with a stepper motor. The end of the tube is at a higher elevation from the launch. The balls are released from the tip to the launching mechanism. The gravitational force (represented at Figure ~\ref{fig:gravity}) provides the transfer to launch. The required frequency is set by a hinge mechanism (Figure ~\ref{fig:hinge_mechanism}), the movement of the hinge mechanism determines the frequency. The 4 wheel mechanism (Figure ~\ref{fig:4wheel}), which is controlled by BLDC motors is benefited to give and control the spin options and speed of the balls. The pitch angle value is controlled by using a four bar mechanism (Figure ~\ref{fig:fourbar}), and yaw angle value is controlled by a gear, which rotates the head (Figure ~\ref{fig:gear2}) . Both controlling mechanisms are connected with servo motors to rotate the head in the desired directions. The trajectory and frequency information are accepted from the user with an integrated controller (Figure ~\ref{fig:integrated}). Accepting numerical information from the user is provided by using an encoder (Figure ~\ref{fig:encoder}). Finally, the user is allowed to fix the device to the table by using clamps (Figure ~\ref{fig:clamp}). \\

\section{Evaluation of Concepts}

The evaluation of criteria was conducted using the Analytic Hierarchy Process (AHP) method. Initially, Saaty's Fundamental scale for pairwise comparison is utilized. This method employs a pairwise comparison approach, which means that each criterion is compared to every other criterion on Saaty's 1-9 scale of relative importance. This scale goes from 1 (equal importance) to 9 (absolute importance), with intermediate values (2, 4, 6, 8) denoting nuanced assessments. Then these values were normalized, and weighted averages were calculated to ensure a consistent and unbiased evaluation framework. \\

In addition to assessing each concept, the evaluation criteria were also applied to analyze the functions and corresponding solutions presented in the morphological chart. For each function, a decision matrix was constructed, and the solution with the highest score in each matrix was identified as the optimal choice for that specific function. This systematic approach ensured that both the overall concepts and individual functions were evaluated objectively.

Our design criteria are as follows:

\begin{enumerate}
    \item \textbf{Serving Frequency:} Can throw 80 balls per minute and more. Also, adjustable within 25-80 balls per minute.
    \item \textbf{Feeding the Ball}: Allows for uninterrupted training with desired frequency.
    \item \textbf{Serving Speed:} Adjustable between 4 m/s and 25 m/s. Can throw balls at 25 m/s and more.
    \item \textbf{Preventing Balls from Escaping:} The design can collect balls that came up to 1 meter height on its side.
    \item \textbf{Selectable Serving Modes:} Supports various training modes.
    \item \textbf{Giving Yaw and Pitch Angle:} Angles need to be adjustable within specified ranges accurately.
    \item \textbf{Portability:} Less than the maximum weight which is 15 kg, easy to set up.
    \item \textbf{Capacity:} Minimum storage of 100 balls.
    \item \textbf{Ball Durability:} Balls should withstand at least 1000 throws.
    \item \textbf{Power Consumption:} Energy efficiency is prioritized.
    \item \textbf{Spin Options:} Ability to generate 36 spins for varied training.
    \item \textbf{User Interface:} It should be easy to use and should not contain complicated buttons.
    \item \textbf{Cost:} The design should be cost efficient, the cost of manufacturing must be less than 300 dolars.
    \item \textbf{No Spin (Bonus):} Throwing should be possible without spin.
    \item \textbf{Different Scenarios (Bonus):} Allow different types of throws, for example starting with a serve.
\end{enumerate}

Based on the design criteria, the evaluation criteria are derived as follows:
\begin{enumerate}
    \item \textbf{Maximum Attainable Serving Frequency:} The highest number of balls the machine can serve per second. Measures the machine's overall capability to serve balls at its highest possible rate, regardless of how the balls are fed. This criterion is derived from the "Serving Frequency" design criterion, as achieving a high maximum frequency ensures the machine can meet a wide range of performance requirements with flexibility for lower frequencies.

    \item \textbf{Serving Frequency Adjustment Accuracy:} The precision of frequency adjustment, measured as deviation from the target frequency. This criterion is also derived from "Serving Frequency," focusing on how accurately the machine can meet specific serving rates, crucial for scenarios that require controlled and consistent ball delivery.

    \item \textbf{Maximum Feeding Speed:} The rate at which the machine loads and serves balls from the reservoir, ensuring continuous and efficient operation without interruptions. Focuses specifically on the efficiency of the feeding mechanism to supply balls into the serving system at a consistent rate. This criterion is derived from the "Feeding the Balls" design criterion, as the ability to achieve a high feeding speed ensures the machine can handle demanding use cases while maintaining a smooth and consistent supply of balls to the serving mechanism.

    \item \textbf{Maximum Attainable Pitch and Yaw Angle:} The highest vertical and horizontal angle the machine can achieve, determining its capability to simulate lobs or high-arc serves and allowing it to target various positions across the table for diverse shot placement. This criterion is derived from the "Giving Yaw and Pitch Angle" design criterion, as evaluating the maximum angles ensures the machine can cover a wide range of shot trajectories and placements, providing versatility and precision in gameplay scenarios.

    \item \textbf{Ball Prevention Efficiency:} The proportion of prevented balls from escaping successfully and transferred to the reservoir. This criterion is derived from the "Preventing Balls from Escaping" design criterion, as it quantifies the effectiveness of the mechanism in retaining balls, ensuring minimal loss during operation and maintaining a consistent supply for serving.

    \item \textbf{Serving Accuracy:} Average deviation of the ball's landing point from the target. This criterion is derived from "Giving Yaw and Pitch Angle," "Serving Speed," and "Feeding the Balls" design criteria, as accurate targeting requires precise control over ball direction, velocity, and feeding consistency. Additionally, it depends on the "Serving Frequency" design criterion to ensure that accuracy is maintained even at the desired serving rates.  

    \item \textbf{Serving Precision:} Consistency of serving, measured as the standard deviation of ball landing points. This criterion is derived from "Giving Yaw and Pitch Angle," "Serving Speed," and "Feeding the Balls" design criteria, as consistent ball placement relies on stable directional control, speed regulation, and feeding. The "Serving Frequency" design criterion also plays a role by ensuring precision is upheld across various serving rates without performance degradation.

    \item \textbf{Maximum Attainable Serving Speed:} The fastest ball velocity the machine can achieve. This criterion is derived from "Feeding the Balls" and "Serving Speed" design criteria, as achieving high serving speeds requires efficient feeding of balls into the serving mechanism and robust control over the velocity imparted to the ball during the serving process.

    \item \textbf{Portability:} Subjective score based on factors such as weight, size, and transportability. This criterion is derived from the "Portability" design criterion, as it assesses how easy it is to move, transport, and store the machine, taking into account the overall design and physical characteristics that influence its mobility.

    \item \textbf{Reservoir Capacity:} Maximum number of balls the reservoir can hold. This criterion is derived from the "Capacity" design criterion, as it measures the machine's ability to store and supply a sufficient number of balls for uninterrupted operation, impacting both performance and convenience during extended use.

    \item \textbf{Ball Durability:} Percentage of wear or deformation observed on balls after a specified number of serves. This criterion is derived from the "Capacity" design criterion, as the ability to store and serve a large number of balls without causing excessive wear or damage directly impacts the longevity and performance of the balls over time.

    \item \textbf{Energy Consumption:} Average power usage during operation. This criterion is derived from the "Power Consumption" design criterion, as it measures the efficiency of the machine in terms of energy usage, reflecting how well the system optimizes power consumption during its operation.

    \item \textbf{Spin Options Variety:} Number of spin types the machine can generate (e.g., topspin, backspin, sidespin). This criterion is derived from the "Spin Options" design criterion, as it evaluates the variety of spin types the machine can produce, which directly affects the range of gameplay scenarios it can simulate.

    \item \textbf{Cost:} Total cost of manufacturing or purchasing the machine. This criterion is derived from the "Cost" design criterion, as it directly reflects the financial aspect of producing or acquiring the machine, factoring in materials, labor, and other associated expenses.
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

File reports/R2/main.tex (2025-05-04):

\documentclass[12pt]{article}
\usepackage{graphicx} % For including graphics
\usepackage{hyperref} % For URLs and hyperlinks
\usepackage{amsmath} % For math symbols
\usepackage{enumitem} % For customized lists
\usepackage{geometry} % For page margins
\usepackage{xcolor} % For colored text
\usepackage{titlesec} % For title formatting
\usepackage{fancyhdr} % For headers
\usepackage{setspace} % For spacing
\usepackage{multirow}
\usepackage{adjustbox} % For scaling the table
\usepackage{array} % For defining column widths and centering
\usepackage{float}
\usepackage{rotating} % For sideways tables
\usepackage{tabularx} % For automatically adjusting column widths
\usepackage{placeins} % For \FloatBarrier
\usepackage{caption}
\usepackage{subcaption}
\usepackage{longtable}
\usepackage{lscape}
\usepackage{booktabs}

% Page setup
\geometry{a4paper, margin=0.75in}
\setlength{\parindent}{0pt} % Remove indentation
\captionsetup{font=scriptsize}

% Header setup
\pagestyle{fancy}
\fancyhf{}
\fancyhead[L]{Group No: C1}
\fancyhead[C]{ME 407 -- Spring 2024}
\fancyhead[R]{\thepage}
\renewcommand{\headrulewidth}{0.4pt}

% Document Title
\begin{document}
\begin{center}
    \vspace{1em}
    \textbf{\LARGE PROBLEM DEFINITION AND DESIGN\\ \vspace{8pt}SPECIFICATIONS}\\
    \vspace{1em}
    \textbf{PROJECT: Design of an Automatic Table Tennis Ball Pitcher}
\end{center}
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

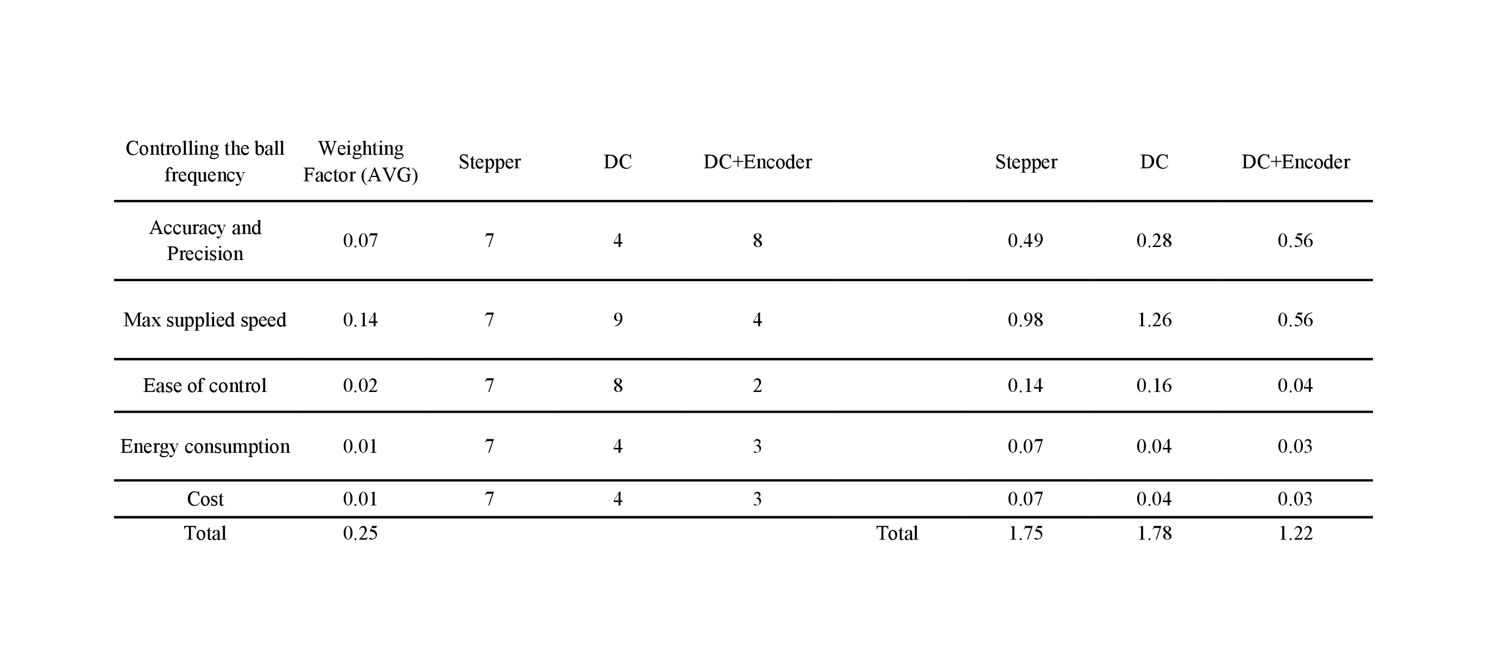
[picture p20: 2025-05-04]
reports/FR/figures/Decision matrices/control frequency.png

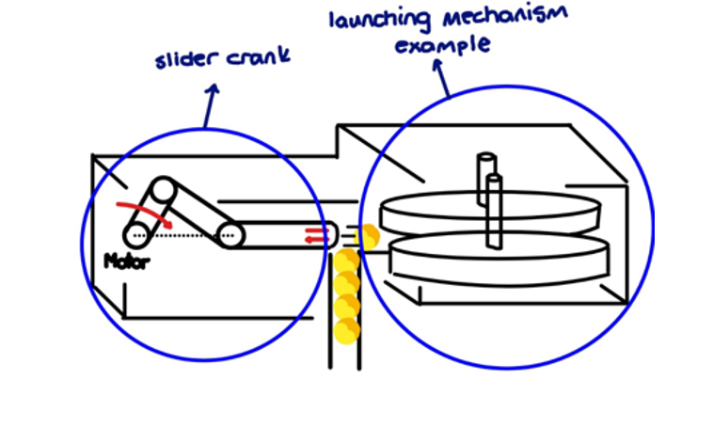
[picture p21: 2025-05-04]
reports/FR/figures/Function photos/Slider Crank.png

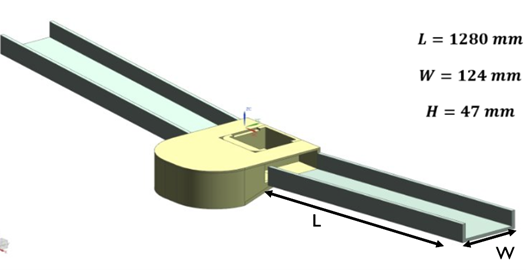
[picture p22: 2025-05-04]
reports/FR/figures/Figures/storage capacity.png

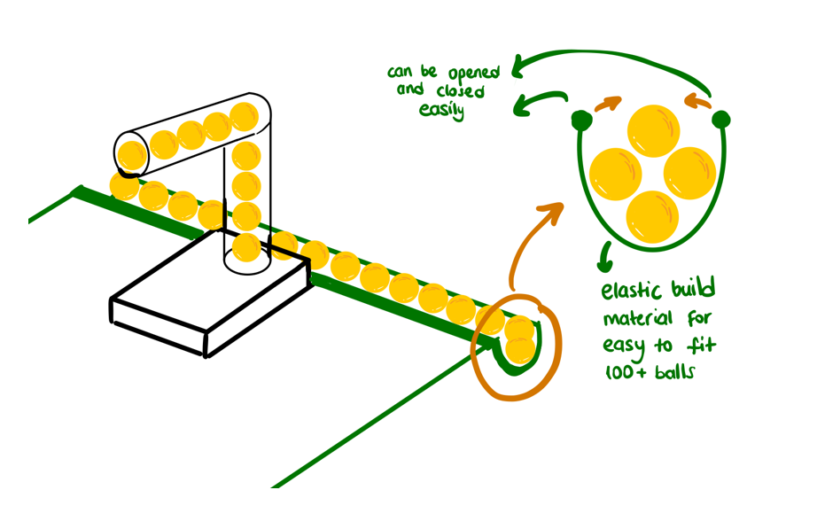
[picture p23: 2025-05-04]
reports/FR/figures/Function photos/groove.png

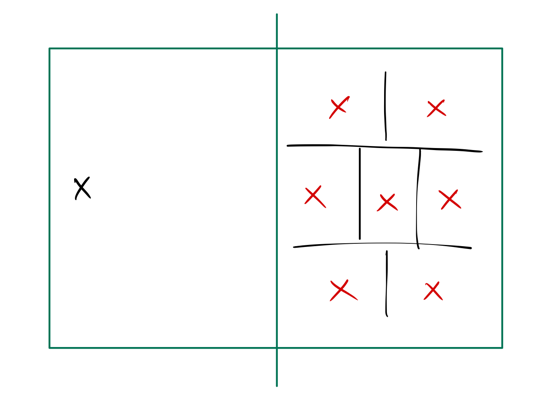
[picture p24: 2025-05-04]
reports/FR/figures/7areaoftable.png

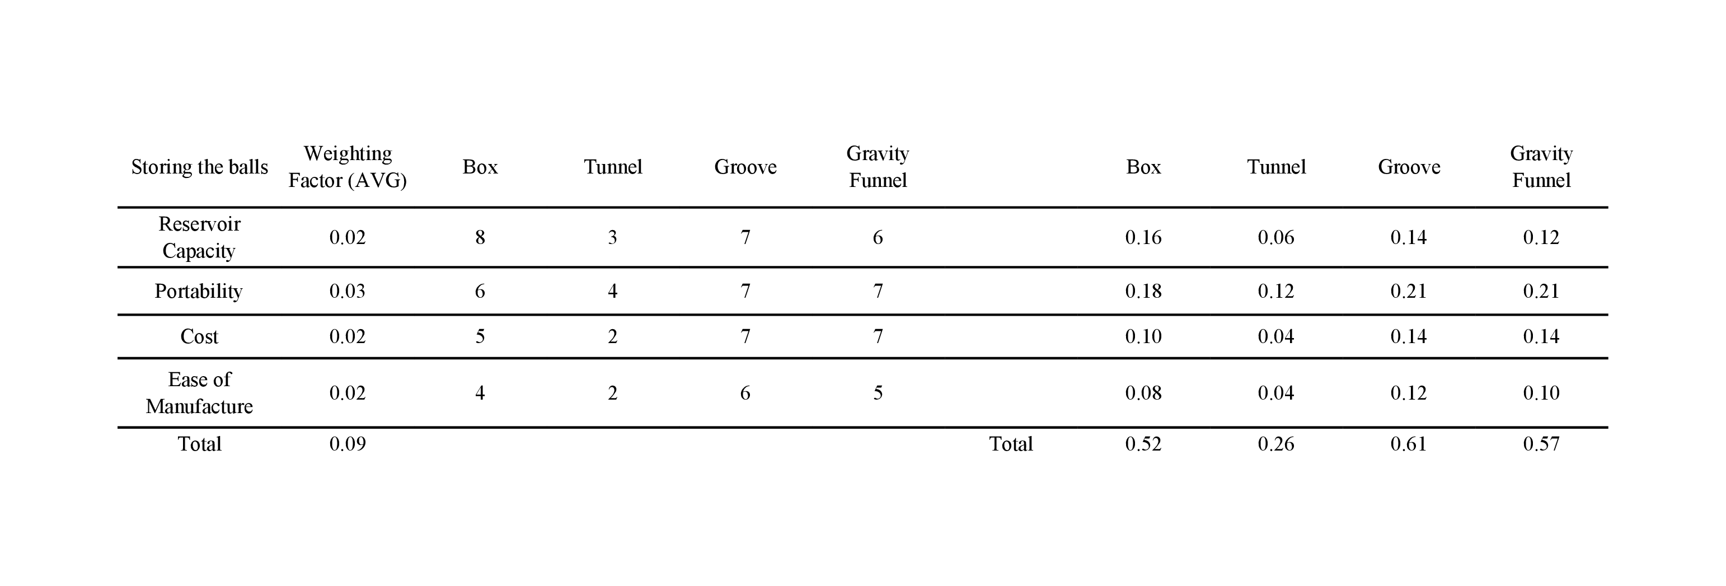
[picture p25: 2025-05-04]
reports/FR/figures/Decision matrices/storing.png

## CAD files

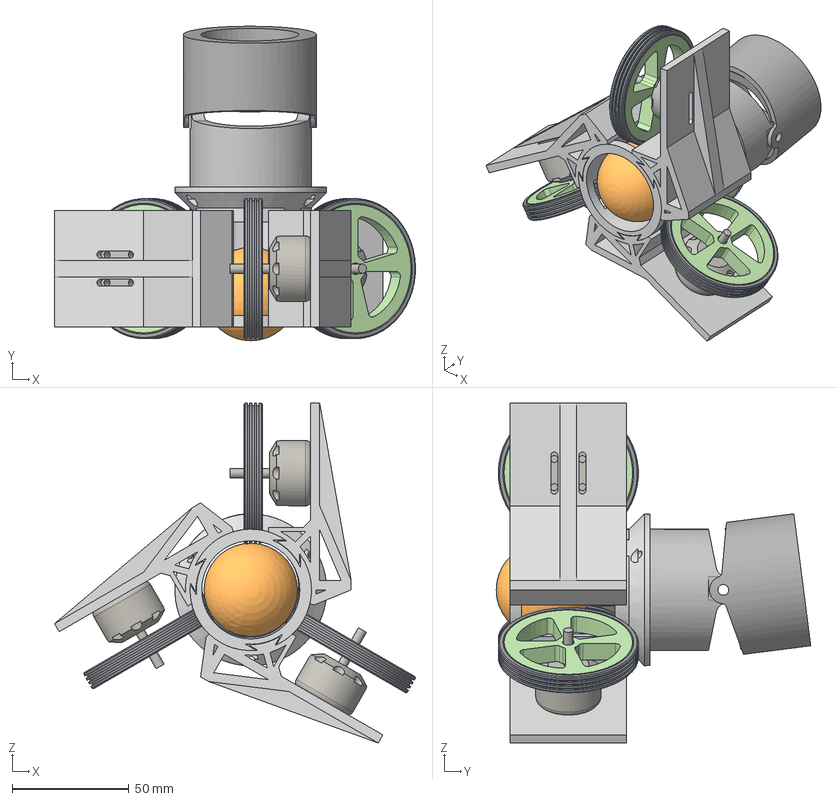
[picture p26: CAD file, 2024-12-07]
hardware/models/launcher_head_assembly.step
154.5 x 134.7 x 145.5 mm
Ball
Pitch Head
Rubber Wheel x 3
MT2204 x 3
Slotted Pipe (Circular)
Flywheel x 3
Motor Attachment (Circular) x 3
Pitch Horizontal

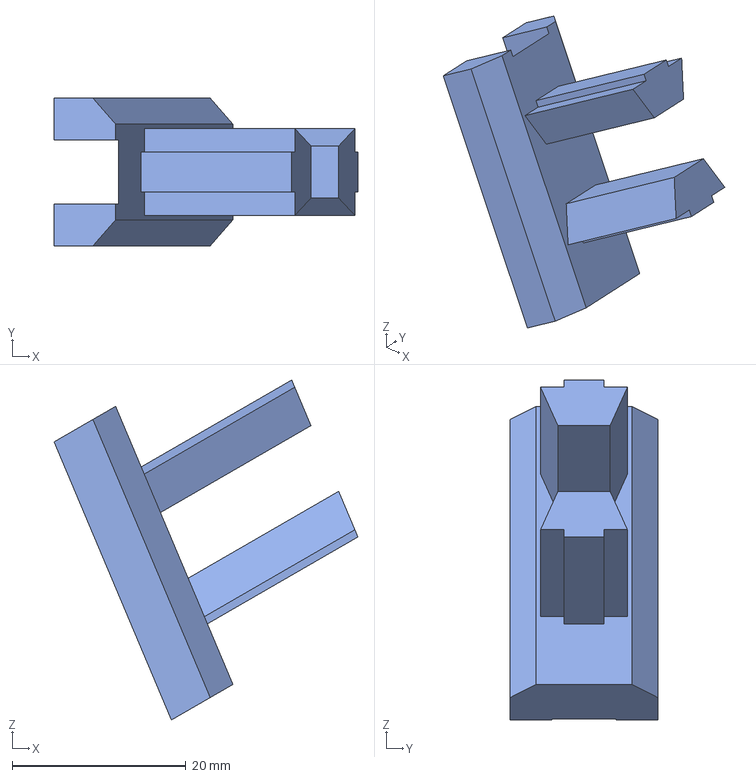
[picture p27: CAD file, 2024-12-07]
hardware/models/launcher_sigma_attachment.step
35.0 x 17.0 x 39.1 mm

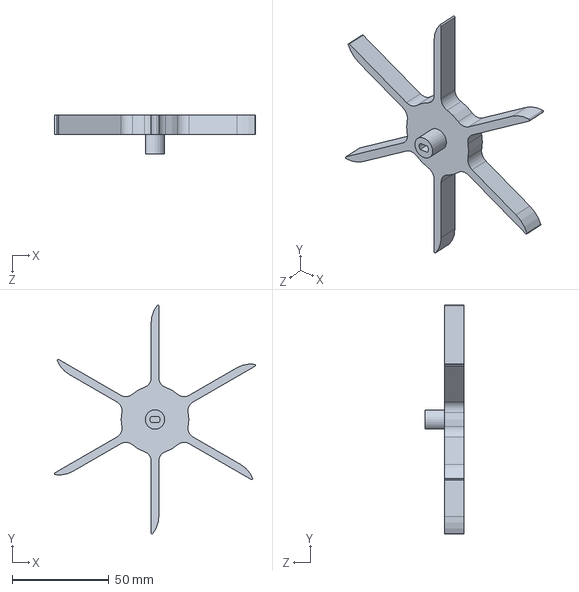
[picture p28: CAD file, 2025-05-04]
hardware/technical_drawings/maltesewheel8 - maltese6[1].SLDPRT
104.0 x 118.3 x 20.0 mm

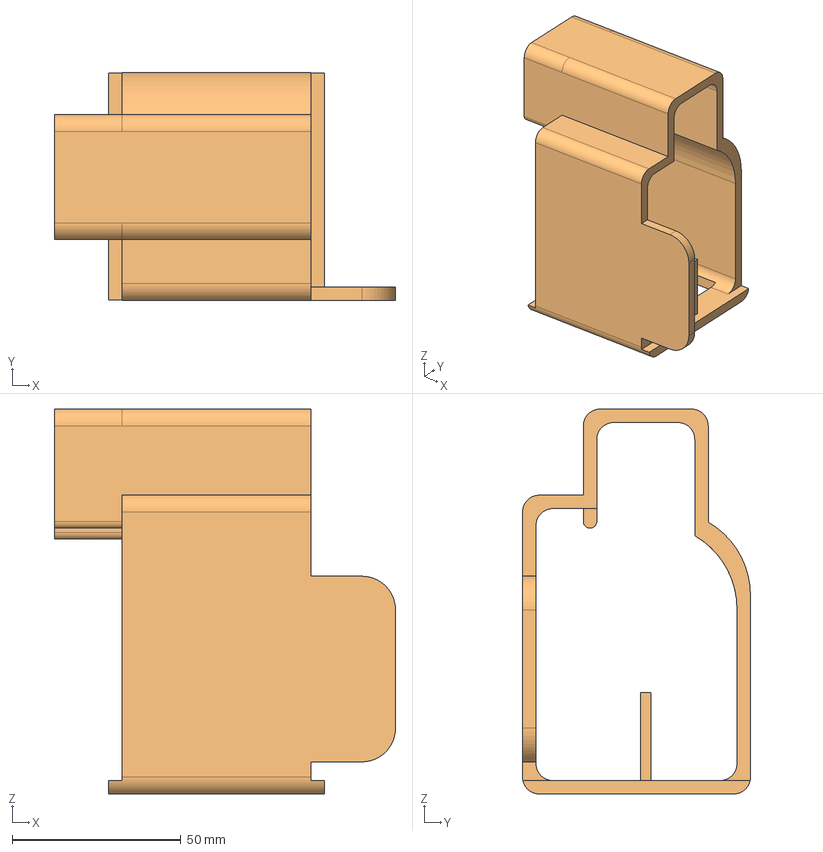
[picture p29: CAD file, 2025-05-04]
hardware/technical_drawings/to print/pitch_box_v5.stp
101.0 x 67.5 x 114.0 mm

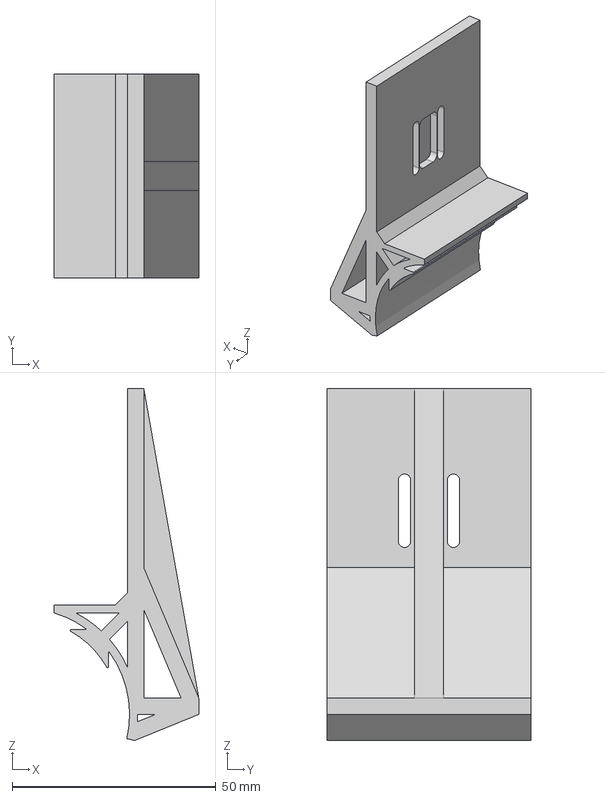
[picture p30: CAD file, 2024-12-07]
hardware/models/launcher_motor_attachment.step
35.5 x 50.0 x 86.4 mm

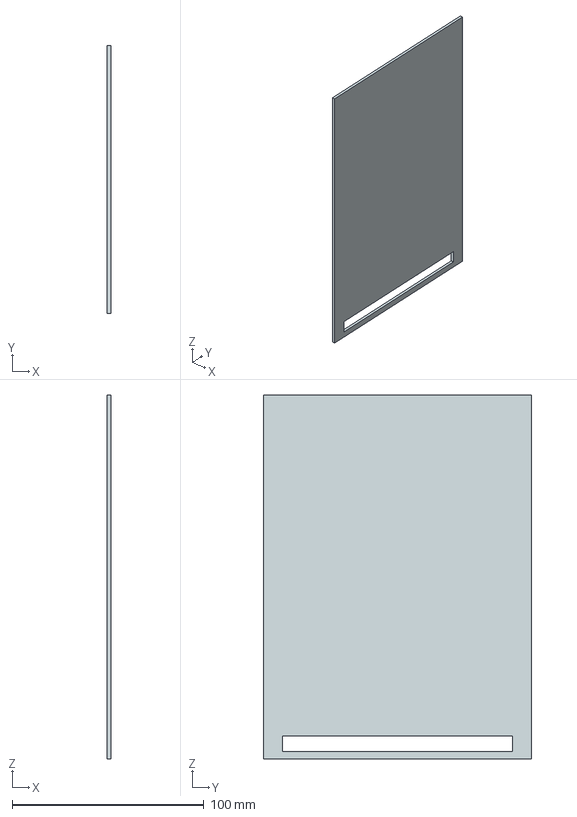
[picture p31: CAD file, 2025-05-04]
hardware/technical_drawings/to print/pertinakskapak.stp
2.00 x 140.0 x 190.0 mm

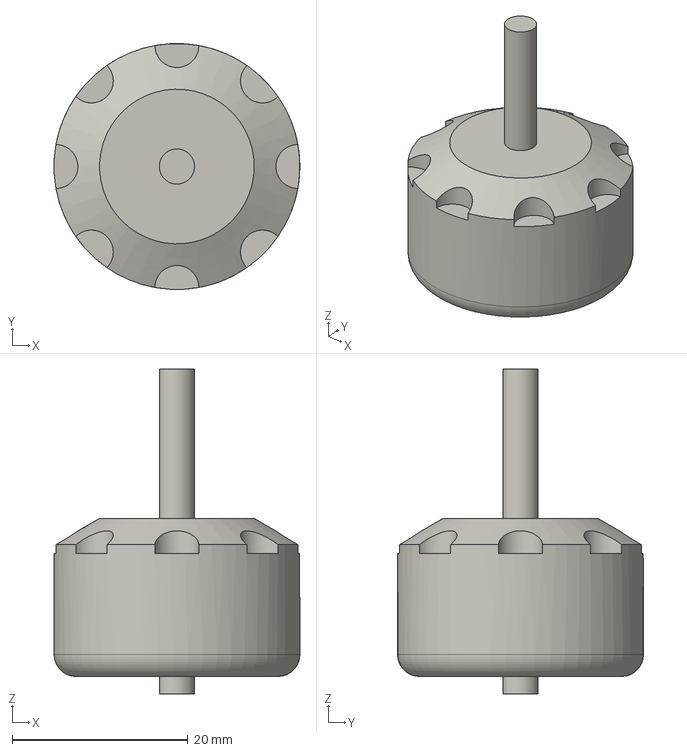
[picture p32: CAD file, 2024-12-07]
hardware/models/launcher_mt2204.step
28.0 x 28.0 x 37.0 mm

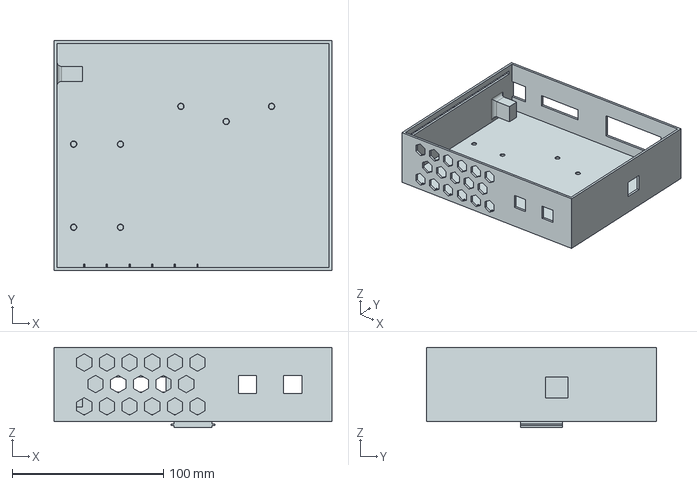
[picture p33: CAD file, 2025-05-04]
hardware/technical_drawings/to print/pertinaks2.stp
184.0 x 152.0 x 53.0 mm

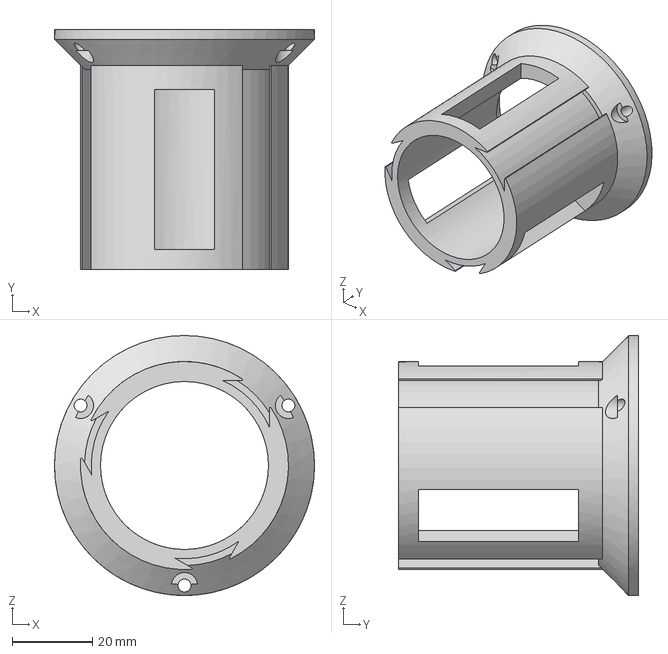
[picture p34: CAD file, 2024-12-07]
hardware/models/launcher_slotted_pipe.step
65.0 x 60.0 x 65.0 mm

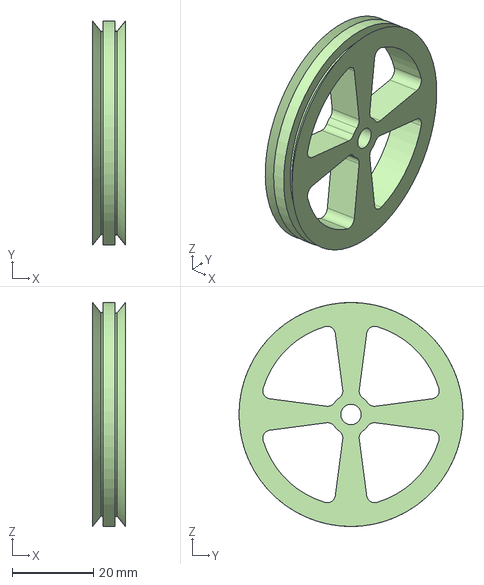
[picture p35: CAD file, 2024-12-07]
hardware/models/launcher_flywheel.step
8.00 x 55.0 x 55.0 mm

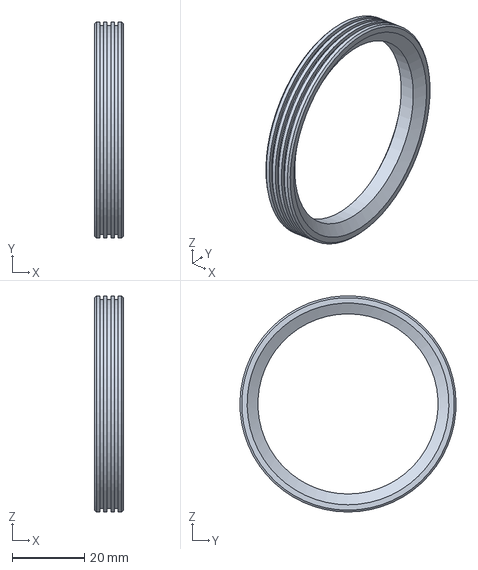
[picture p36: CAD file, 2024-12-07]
hardware/models/launcher_rubber_wheel.step
8.00 x 60.0 x 60.0 mm

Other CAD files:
hardware/technical_drawings/2 2 M4 2Hole Bearing Cap.prt
hardware/technical_drawings/2-3-M4 Bearing Cap.prt
hardware/technical_drawings/28bjy-48_step.prt
hardware/technical_drawings/28bjy-48_step.prt_Varsayılan.prt
hardware/technical_drawings/4668K284_Permanently Lubricated Stainless Steel Ball Bearing_step.prt
hardware/technical_drawings/Component2 _1__step.prt
hardware/technical_drawings/Feeding Holder.prt
hardware/technical_drawings/FeedingMechanism.prt
hardware/technical_drawings/Flywheel - Flywheel_step.prt
hardware/technical_drawings/Flywheel.prt
hardware/technical_drawings/Head Assembly - PH Pan head screw M3x0.50 x 16_step.prt
hardware/technical_drawings/Head Assembly _1__step.prt
hardware/technical_drawings/Head Assembly_step.prt
hardware/technical_drawings/L_mounting_plate.prt
hardware/technical_drawings/MG996R v6 _1__step.prt
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

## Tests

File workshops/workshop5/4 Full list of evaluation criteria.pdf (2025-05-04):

Overall Design Criteria
1. Maximum Attainable Serving Frequency
2. Adjustment Accuracy of Serving Frequency
3. Automatic Feeding at Certain Frequency
4. Collecting Properly Returned Balls into the reservoir
5. Serving Accuracy and Precision
6. Maximum Attainable Serving Speed
7. Selectable Serving Modes
8. Adjustment Accuracy of Pitch and Yaw Angle
9. Ease of control
10. Portability
11. Capacity
12. Ball Durability
13. Power Consumption
14. Spin Options
15. Cost
16. Ease of manufacture

Functions’ Criteria
1. Accuracy and Precision
2. Response Time
3. Adjustability
4. Component compatibility
5. Ease of manufacture
6. Cost
7. Ease of control
8. Energy Consumption
9. Max rotation speed
10. Transfer speed
11. Capture Rate
12. Portability
13. Capacity
a. Smooth Flow without Jamming
b. Maximum Transfer Speed

Subfunction Extra Design Criteria

17. Adjustment rate: Adjusting a parameter is important. However, this process occurs in time. Hence, the faster the better.
18. Adjustability: Derived from the adjustable serving speed/spin/frequency criterias.
19. Component compatibility: some solutions are more flexible and can be used with different combinations of the concepts.

20. Max rotation speed: important parameter for motors
21. Energy consumption: derived from power consumption
22. User friendliness: most user interfaces are mainly designed considering this criteria. However, it is not important for any other part of the system.
23. Appearance: Appearance of the user interface. It affects the choice of the customer while buying a device.
24. Precision: comes from accuracy and precision
25. Capture rate: important selection criteria for catching concept selection, but not apply to any other part of the system.
26. Transfer speed: derived from frequency
27. Efficiency: Important for continuous operation (for the ball transfer to the launch)
28. Ease of loading: Important for storing.
29. Ball recyclability: Recycling the balls occurs at the storage only. For automatiza the more the better.

Cost: An engineering product that will be produced and sold must be profitable for the producer/ manufacturer and affordable for the customer.

Ease of manufacture: Sometimes a solution may look as the perfect candidate to meet the customer needs. However, it may not be very easy to manufacture for the producer at that instant. For example, a company's current manufacturing abilities or contracted manufacturers may not have the technology/ device which requires another contraction or machine installation. In such a situation, instead of disregarding this solution we can keep it in our possible solution list for later use.

User interface: Bonus criteria for the project. Creating a user interface and making it simple to use will improve customer satisfaction.

Ease of control: Controllability of an automatic device is crucial.

EVALUATION CRITERIA (29.11.2024)
1. Maximum Attainable Serving Frequency: The highest number of balls the machine can serve per second. Measures the machine's overall capability to serve balls at its highest possible rate, regardless of how the balls are fed.
2. Serving Frequency Adjustment Accuracy (%): The precision of frequency adjustment, measured as deviation from the target frequency.
3. Maximum Feeding Speed: The rate at which the machine loads and serves balls from the reservoir, ensuring continuous and efficient operation without interruptions. Focuses specifically on the efficiency of the feeding mechanism to supply balls into the serving system at a consistent rate.
4. Maximum Attainable Pitch Angle (degrees): The highest vertical angle the machine can achieve, determining its capability to simulate lobs or high-arc serves.
5. Maximum Attainable Yaw Angle (degrees): The widest horizontal angle the machine can reach, allowing it to target various positions across the table for diverse shot placement.
6. Ball Prevention Efficiency (%): The proportion of prevented balls from escaping successfully and transferred to the reservoir.
7. Serving Accuracy (cm deviation): Average deviation of the ball's landing point from the target.
8. Serving Precision (cm spread): Consistency of serving, measured as the standard deviation of ball landing points.
9. Maximum Attainable Serving Speed (m/s): The fastest ball velocity the machine can achieve.
10. Serving Modes Variety (count): The total number of distinct serving modes available.
11. Portability(1-10): Subjective score based on factors such as weight, size, and transportability.
12. Reservoir Capacity (balls): Maximum number of balls the reservoir can hold.
13. Ball Durability: Percentage of wear or deformation observed on balls after a specified number of serves.
14. Energy Consumption: Average power usage during operation.
15. Spin Options Variety: Number of spin types the machine can generate (e.g., topspin, backspin, sidespin).
16. Cost: Total cost of manufacturing or purchasing the machine.
17. Ease of Manufacturing: A subjective score reflecting the ease or difficulty of manufacturing the machine.
18. Response Time (seconds): The time the system takes to reach its target value after a command, indicating its speed and efficiency.
19. User Friendliness: It focuses on the clarity of the controls, the simplicity of the process, and how quickly a user can achieve desired outcomes without confusion or excessive effort.
20. Ease of Control: It evaluates how straightforward and intuitive it is to manage, adjust, or optimize the system during development and operation, ensuring minimal complexity and effort.

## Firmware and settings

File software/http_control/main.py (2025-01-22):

import network
import socket
import math
import time
import random
from bldc import ESC
from servo import Servo
from stepper import Stepper


class TennisBallPitcherHTTP:
    def __init__(self):
        # Initialize motors
        self.esc1 = ESC(pwm_pin=18)
        self.esc2 = ESC(pwm_pin=19)
        self.esc3 = ESC(pwm_pin=20)
        self.pitch_servo = Servo(pwm_pin=15, gear_ratio=86 / 26, angle_shift=90, angle_range=70)
        self.yaw_servo = Servo(pwm_pin=14, gear_ratio=2 / 1, angle_shift=90, angle_range=90)
        self.stepper_motor = Stepper(step_pin=17, dir_pin=16)

        # Stored configuration
        self.config = {
            "speed": 0,
            "frequency": 0,
            "yaw": 0,
            "pitch": 0,
            "spin": 0,
            "spin_angle": 0,
        }

    def stop_all_motors(self):
        """Stop all motors."""
        self.esc1.stop()
        self.esc2.stop()
        self.esc3.stop()
        self.stepper_motor.stop()
        return "All motors stopped."

    def send(self, speed, frequency, yaw, pitch, spin, spin_angle):
        """Save configuration for shooting."""
        self.config.update({
            "speed": speed,
            "frequency": frequency,
            "yaw": yaw,
            "pitch": pitch,
            "spin": spin,
            "spin_angle": spin_angle,
        })
        return f"Configuration saved: Speed={speed}, Frequency={frequency}, Yaw={yaw}, Pitch={pitch}, Spin={spin}, Spin Angle={spin_angle}"

    def shoot(self, num_balls):
        """Shoot balls using the saved configuration."""
        speed = self.config["speed"]
        frequency = self.config["frequency"]
        yaw = self.config["yaw"]
        pitch = self.config["pitch"]
        spin = self.config["spin"]
        spin_angle = self.config["spin_angle"]

        # Set yaw and pitch
        self.pitch_servo.set_angle(-pitch)
        self.yaw_servo.set_angle(yaw)

        # Calculate motor speeds for spin effect
        spin_angle_rad = math.radians(spin_angle)
        bottom_speed = speed + spin * math.cos(spin_angle_rad - math.radians(270))
        right_top_speed = speed + spin * math.cos(spin_angle_rad - math.radians(30))
        left_top_speed = speed + spin * math.cos(spin_angle_rad - math.radians(150))

        # Set motor speeds
        self.esc1.set_throttle(bottom_speed)
        self.esc2.set_throttle(right_top_speed)
        self.esc3.set_throttle(left_top_speed)

        # Simulate ball shooting
        feed_time = 60 / frequency
        for _ in range(num_balls):
            self.stepper_motor.move(rpm=frequency / 6, rotations=1 / 6, direction=1)
            time.sleep(feed_time)

        self.stop_all_motors()
        return f"{num_balls} balls shot with saved configuration."

    def random(self, num_balls):
        """Shoot balls with random parameters."""
        for _ in range(num_balls):
            speed = random.randint(1060, 1200)
            frequency = random.randint(5, 20)
            yaw = random.uniform(-25, 25)
            pitch = random.uniform(-15, 15)
            spin = random.randint(-300, 300)
            spin_angle = random.uniform(0, 360)
            self.send(speed, frequency, yaw, pitch, spin, spin_angle)
            self.shoot(1)  # Shoot one ball per random configuration
        return f"Random mode executed: {num_balls} balls shot with random parameters."


# Wi-Fi and HTTP server setup
def start_server():
    wlan = network.WLAN(network.STA_IF)
    wlan.active(True)
    wlan.connect("Salih", "wcgw0031")

    while not wlan.isconnected():
        pass

    print("Connected to Wi-Fi:", wlan.ifconfig())

    addr = socket.getaddrinfo("0.0.0.0", 80)[0][-1]
    server_socket = socket.socket()
    server_socket.bind(addr)
    server_socket.listen(5)
    print("Listening on:", addr)

    pitcher = TennisBallPitcherHTTP()

    while True:
        client_socket, client_address = server_socket.accept()
        request = client_socket.recv(1024).decode("utf-8")
        print("Request:", request)

        # Parse the request
        request_line = request.split("\r\n")[0]
        method, path, _ = request_line.split(" ")
        response = "Invalid command"

        if method == "GET":
            query = path[2:]  # Remove "/?"
            command, *params = query.split(",")

            try:
                if command == "send":
                    response = pitcher.send(
                        int(params[0]), int(params[1]), int(params[2]),
                        int(params[3]), int(params[4]), int(params[5])
                    )
                elif command == "shoot":
                    response = pitcher.shoot(int(params[0]))
                elif command == "random":
                    response = pitcher.random(int(params[0]))
                elif command == "off":
                    response = pitcher.stop_all_motors()
                else:
                    response = "Unknown command"
            except Exception as e:
                response = f"Error processing command: {e}"

        # Send the HTTP response
        print("Response:", response)
        client_socket.send(f"HTTP/1.1 200 OK\r\nContent-Type: text/plain\r\n\r\n{response}".encode())
        client_socket.close()


if __name__ == "__main__":
    start_server()

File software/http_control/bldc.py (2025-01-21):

import time
from machine import Pin, PWM

class ESC:
    def __init__(self, pwm_pin, freq=50, min_throttle=1000, max_throttle=2000, min_running_throttle = 1080):
        """
        Initialize the ESC class.

        :param pwm_pin: GPIO pin number for the PWM signal
        :param freq: PWM frequency in Hz (default: 50 Hz for most ESCs)
        :param min_throttle: Minimum throttle value (default: 1000)
        :param max_throttle: Maximum throttle value (default: 2000)
        """
        self.pwm = PWM(Pin(pwm_pin))
        self.pwm.freq(freq)

        self.min_throttle = min_throttle
        self.max_throttle = max_throttle
        self.min_running_throttle = min_running_throttle

        # Initialize ESC at minimum throttle
        self.set_throttle(self.min_throttle)

    def _throttle_to_duty(self, throttle):
        """
        Convert throttle value to a duty cycle.

        :param throttle: Throttle value between min_throttle and max_throttle
        :return: Duty cycle as an integer
        """
        pulse_width = throttle / 1e6  # Convert throttle to seconds (e.g., 1500 -> 0.0015)
        duty = int(pulse_width * self.pwm.freq() * 65535)
        return duty

    def set_throttle(self, throttle):
        """
        Set the ESC throttle.

        :param throttle: Throttle value between min_throttle and max_throttle
        """
        if throttle < self.min_throttle or throttle > self.max_throttle:
            print(f"Throttle must be between {self.min_throttle} and {self.max_throttle}.")
            throttle = min(max(throttle, self.min_throttle), self.max_throttle)

        duty = self._throttle_to_duty(self.min_running_throttle)
        self.pwm.duty_u16(duty)

        time.sleep(0.1)
        
        duty = self._throttle_to_duty(throttle)
        self.pwm.duty_u16(duty)

    def stop(self):
        """Stop the ESC by setting throttle to minimum."""
        self.set_throttle(self.min_throttle)

    def deinit(self):
        """Stop the PWM signal to the ESC."""
        self.pwm.deinit()

# CLI for controlling ESCs
def main():
    esc1 = ESC(pwm_pin=18)
    esc2 = ESC(pwm_pin=19)
    esc3 = ESC(pwm_pin=20)

    print("ESC CLI initialized. Type 'help' for commands.")

    try:
        while True:
            command = input("Enter command (e.g., 'set 1 1500', 'stop', 'exit'): ")

            if command.startswith("set"):
                # Parse the command
                parts = command.split()
                if len(parts) == 3:
                    esc_number = int(parts[1])
                    throttle = int(parts[2])

                    if esc_number == 1:
                        esc1.set_throttle(throttle)
                    elif esc_number == 2:
                        esc2.set_throttle(throttle)
                    elif esc_number == 3:
                        esc3.set_throttle(throttle)
                    else:
                        print("Invalid ESC number. Use 1, 2, or 3.")
                else:
                    print("Invalid command format. Use 'set <esc_number> <throttle>'.")

            elif command == "stop":
                esc1.stop()
                esc2.stop()
                esc3.stop()
                print("All ESCs stopped.")

            elif command == "exit":
                print("Exiting CLI and deinitializing ESCs...")
                esc1.deinit()
                esc2.deinit()
                esc3.deinit()
                break

            elif command == "help":
                print("""
Available commands:
- set <esc_number> <throttle>: Set throttle value for a specific ESC (e.g., 'set 1 1500').
- stop: Stop all ESCs.
- exit: Exit the program and deinitialize ESCs.
- help: Show this help message.
                """)

            else:
                print("Unknown command. Type 'help' for available commands.")

    except KeyboardInterrupt:
        print("\nExiting CLI and deinitializing ESCs...")
        esc1.deinit()
        esc2.deinit()
        esc3.deinit()

if __name__ == "__main__":
    main()

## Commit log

2024-12-07 launcher models
    [launcher_flywheel.step, launcher_head_assembly.step, launcher_motor_attachment.step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]
2025-05-04 add v1
    [2 2 M4 2Hole Bearing Cap.prt, 2-3-M4 Bearing Cap.prt, 4668K284_Permanently Lubricated Stainless Steel Ball Bearing_step.prt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]
2025-05-04 add v2
    [28bjy-48_step.prt, FeedingMechanism.prt, Main Body Bottom.prt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]
2025-05-04 add v3
    [28bjy-48_step.prt_Varsayılan.prt, PVC_pipe.prt, PVC_pipie_new.prt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]
2025-05-04 add v4
    [28bjy-48_step.prt, FeedingMechanism.prt, Flywheel.prt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]
2025-05-04 add v5
    [Pitch Angle Horizontal Part.prt, assembly1.prt, box_assembly.prt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]
2025-05-04 add v6
    [Flywheel.prt, L_mounting_plate.prt, MT2204.prt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]
2025-05-04 add v7
    [2 2 M4 2Hole Bearing Cap.prt, 2-3-M4 Bearing Cap.prt, Feeding Holder.prt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]
2025-05-04 add v8
    [Shaft Head - Spur gear _65 teeth_ _1__step.prt, assembly1.prt, assembly2.prt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]
2025-05-04 add v9
    [PitchPinion.prt, assembly1.prt, assembly2.prt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]
2025-05-04 add v10
    [Flywheel.prt, MT2204.prt, Main Body Bottom.prt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]
2025-05-04 add v11
    [Main Body Bottom.prt, Main Body Top.prt, box_v7.prt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]
2025-05-04 add v13
    [Component2 _1__step.prt, FeedingMechanism.prt, Flywheel - Flywheel_step.prt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]
